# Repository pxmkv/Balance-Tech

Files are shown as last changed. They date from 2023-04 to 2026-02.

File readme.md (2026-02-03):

# Balance-Tech — Reaction-Wheel Self-Balancing Bike (ESP32 + LQR)

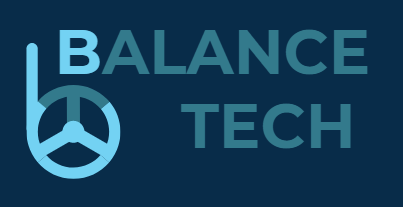
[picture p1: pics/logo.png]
Balance-Tech


A two-wheel self-balancing object reminiscent of a motorcycle, with the ability to **move** and **turn**.  
Balancing is achieved using a **reaction (momentum) wheel** driven by a motor, with a **Kalman filter** for tilt estimation and **LQR state feedback** for control.

> **Safety:** the firmware stops the momentum wheel motor when the tilt exceeds **22°**.

---

## Demo / Photos

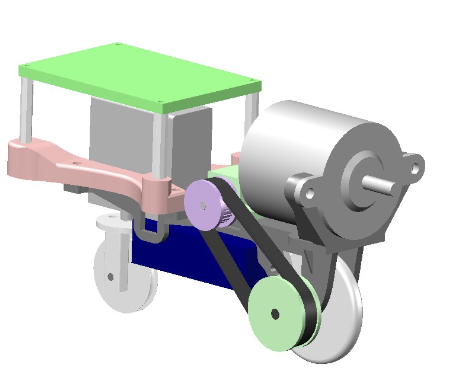
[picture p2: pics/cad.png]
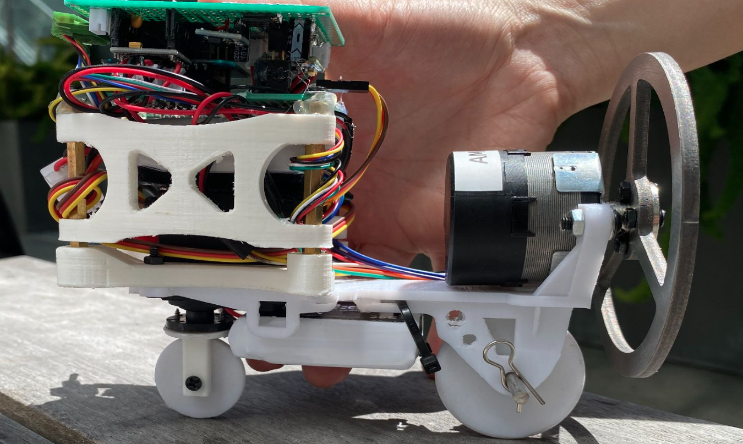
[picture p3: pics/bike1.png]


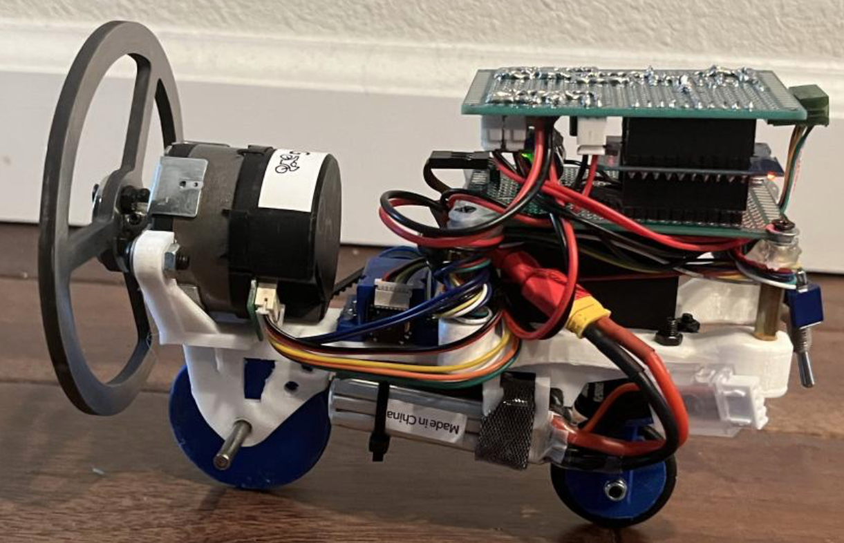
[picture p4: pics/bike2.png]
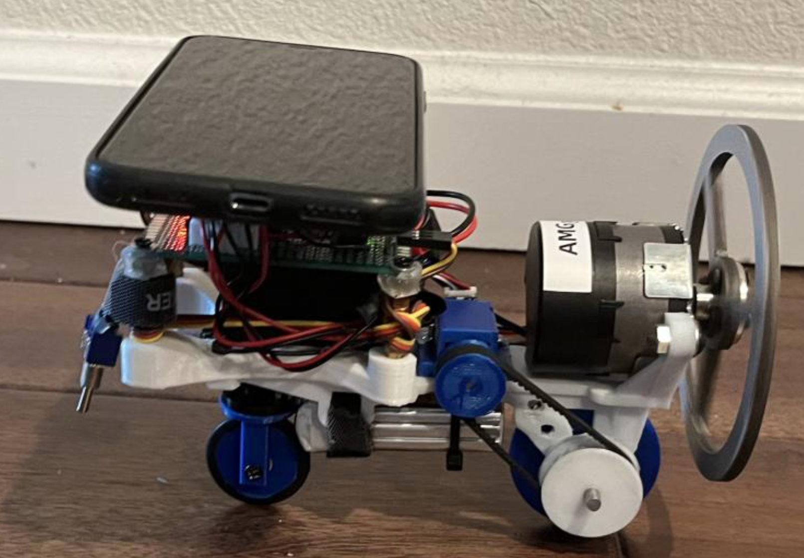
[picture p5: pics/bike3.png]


**Integrated device with labeled actuators and sensors:**

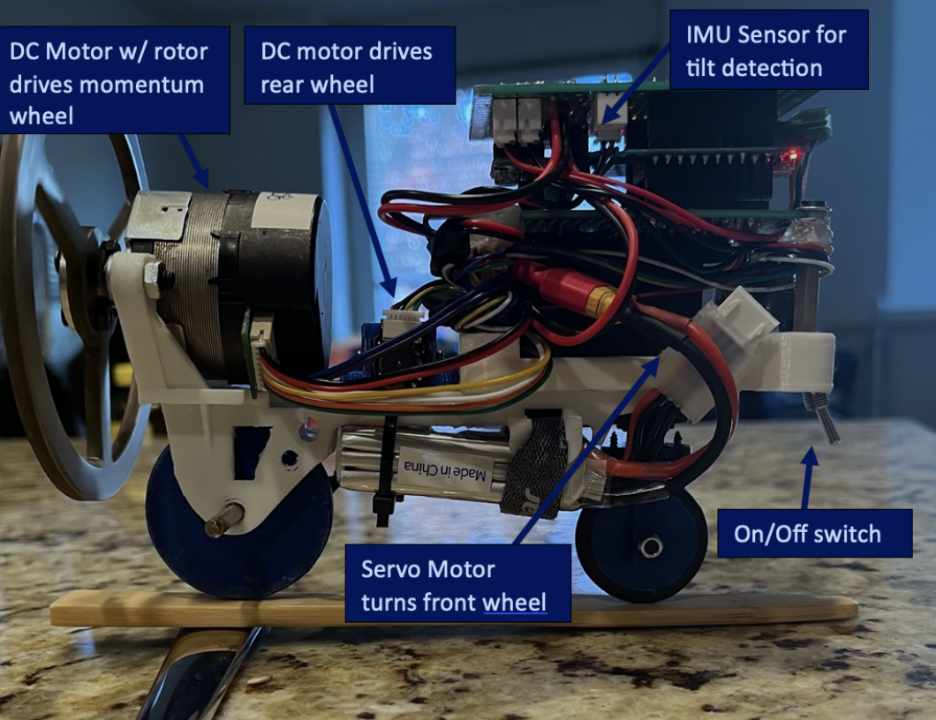
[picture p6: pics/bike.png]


---

## System overview

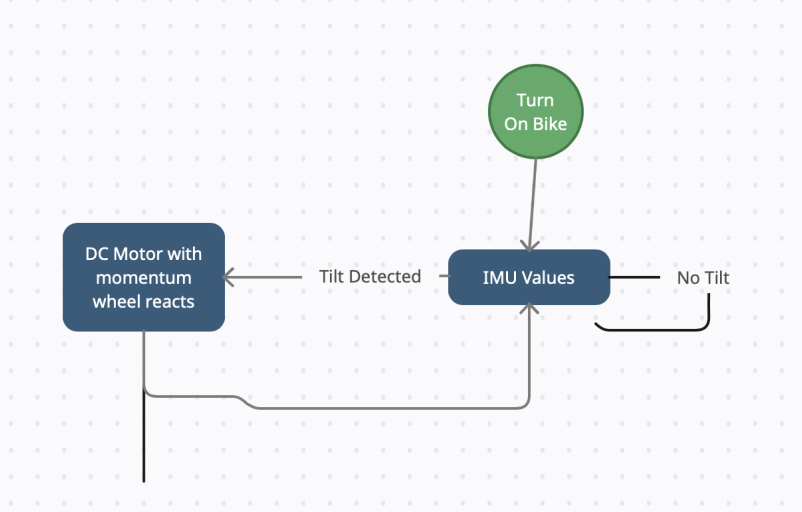
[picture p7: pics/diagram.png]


**Mechanical/coordinate model used in the derivation:**

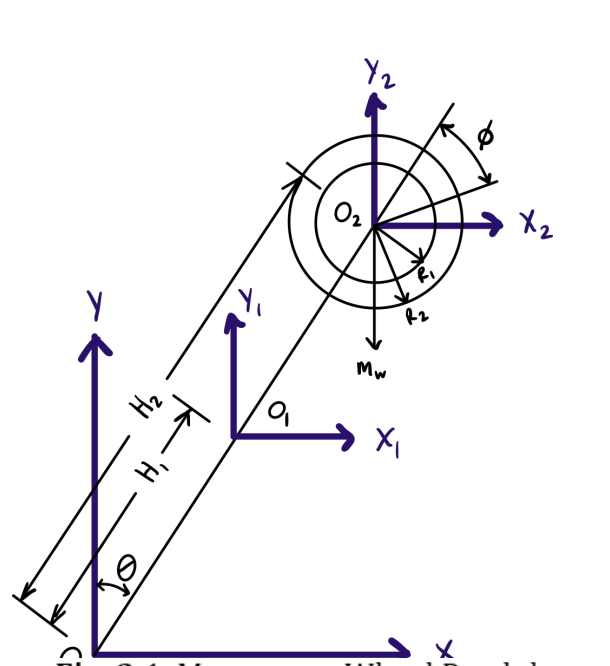
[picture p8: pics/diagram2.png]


**Electronics stack (as built):**

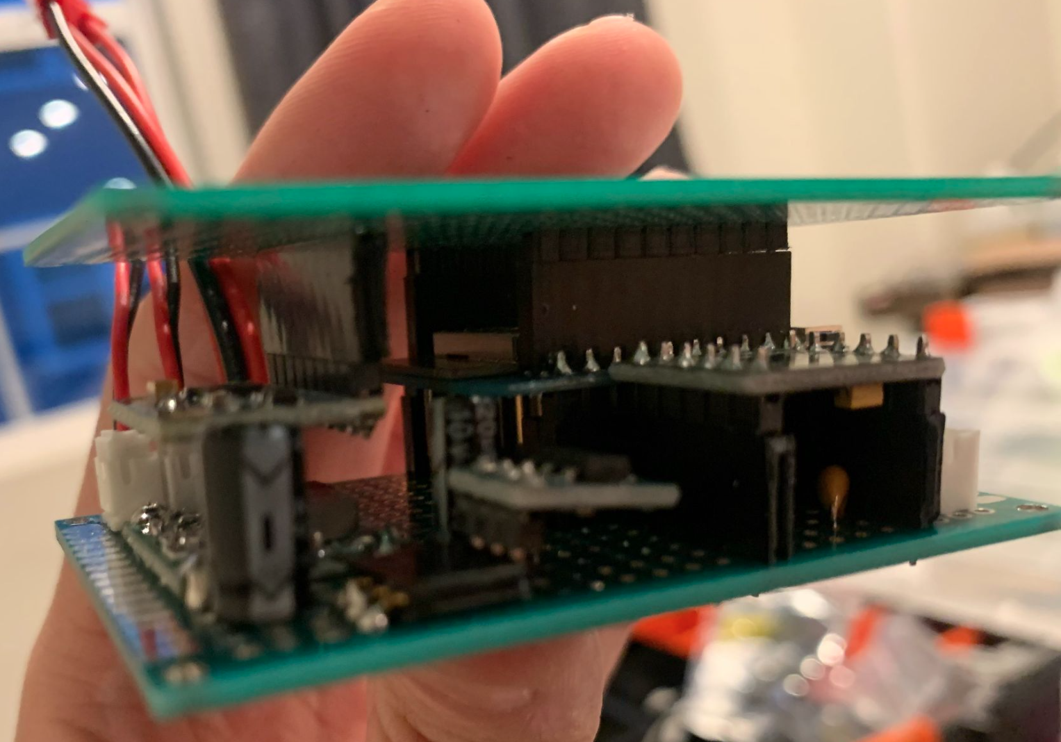
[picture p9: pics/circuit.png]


The bulk of the circuit design lies within a three “story” structure: three circuit boards with ~1 inch spacing.  
Battery power is wired low to reduce center of mass. A buck converter provides adjustable supply and an AMS1117 (DS1117) provides regulation for the MCU.

---

## Repository layout

- `readme.md` — this document  
- `main_LQR/` — Arduino firmware (`main_LQR.ino`) + MATLAB/LQR notes (`main_LQR/readme.md`)
- `schematic/` — wiring reference (PDF)
- `pics/` — images used by the README
- `CAD Files/` — SolidWorks files
- `STL Files/` — printable STLs
- `datasheet/` — key component datasheets
- `LICENSE` — BSD-2-Clause

---

## Hardware

### Actuators
- **Momentum wheel motor**: generates stabilizing torque by accelerating/decelerating the wheel.
- **Rear drive motor**: propels the bike forward/backward.
- **Steering servo**: turns the front wheel.

### Sensors
- **IMU**: MPU6050 (code) / MPU-6000 class (see datasheet)
- **Quadrature encoder** on the momentum wheel motor (speed + position)

### Controller
- **MCU**: WeMOS D1 mini ESP32 (ESP-WROOM-32)

Board reference:

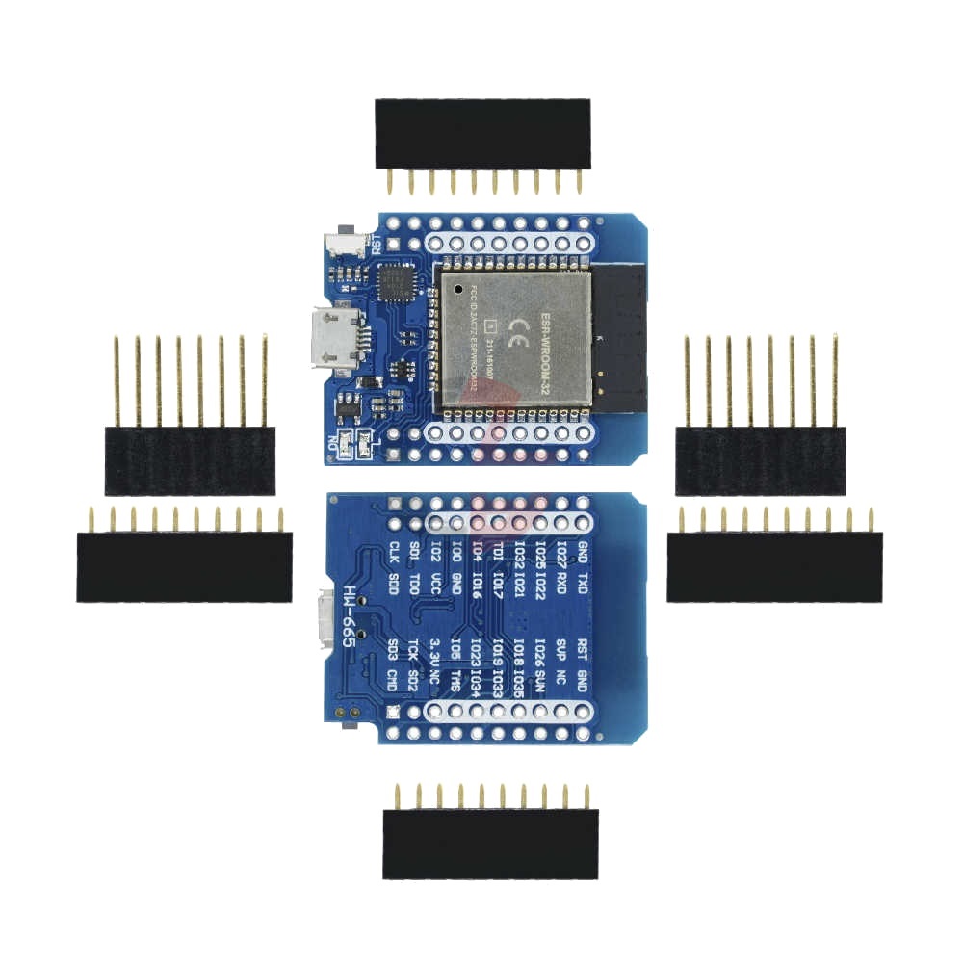
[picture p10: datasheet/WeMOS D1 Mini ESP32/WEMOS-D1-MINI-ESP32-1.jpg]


---

## Wiring / Pin map (firmware defaults)

| Function | GPIO | Notes |
|---|---:|---|
| Momentum wheel PWM | 26 | 20 kHz PWM (`ledc`) |
| Momentum wheel enable/switch | 18 | `M_SW` |
| Momentum wheel direction | 5 | `M_Dir` |
| Encoder A / B | 19 / 23 | `ESP32Encoder.attachHalfQuad(19, 23)` |
| Drive motor PWM (H-bridge) | 33 / 4 | 5 kHz (`D1=33`, `D2=4`) |
| Steering servo PWM | 17 | 50 Hz (`servoChannel`) |
| IMU I²C | SDA=21, SCL=22 | `Wire.begin()` defaults |

Full wiring PDF: [`schematic/sch(just for reference).pdf`](schematic/sch(just%20for%20reference).pdf)

---

## Firmware: build & run

### Toolchain
- Arduino IDE or PlatformIO (Arduino framework)
- Board: “ESP32 Dev Module” (or compatible)

### Libraries
- `ESP32Encoder`
- `I2Cdev` + `MPU6050`
- `Bluepad32`

### Runtime steps
1. Power on the bike.
2. Connect a Bluetooth gamepad (Bluepad32).
3. Calibrate upright offset:
   - **Gamepad:** press **Y + B** (sets `offset = agx`)
   - **Serial:** send `c` (also sets `offset = agx`)
4. Balancing loop runs at ~100 Hz (`loop_time = 10 ms`).

---

## CPU / task structure (ESP32 dual-core)

The firmware pins the remote/gamepad task to core 0, while the balancing loop runs on core 1:

- **CPU Core 1 (`loop`)**
  - Kalman filter (MPU6050 accel + gyro fusion)
  - State computation and LQR control
- **CPU Core 0 (`remote` task)**
  - Read game controller input via Bluepad32
  - Map throttle/brake to drive motor
  - Map joystick to steering servo
  - Provide quick offset calibration via Y+B

---

## Live tuning (Serial)

Send newline-terminated commands:

- `a<value>` → set `K1`
- `s<value>` → set `K2`
- `d<value>` → set `K3`
- `f<value>` → set `K4`
- `o<value>` → set `offset`
- `c` → calibrate (`offset = agx`)

Example:

```txt
a120
s10
d5
f2
```

---

## Control architecture

### State estimation
The IMU provides raw accel/gyro. The code:
- Computes accel tilt (deg) using `atan()`
- Integrates gyro to emphasize short-term dynamics
- Applies a simple Kalman update to fuse accel + gyro (`Kalman_filter()`)

Balancing loop states used in control:
- `euler_angle` (deg): computed as `-agx + offset`
- `gyroXfilter` (deg/s): low-pass filtered angular rate
- `motor_speed` (encoder ticks per loop): `enc_count` each loop
- `motor_pos` (encoder tick accumulator): clamped to `[-110, 110]`

> **Important:** the implementation mixes units (**degrees**, **deg/s**, and **encoder ticks**).  
> The resulting “LQR gains” in firmware should be treated as **tuned state-feedback gains** for these units.

#### Kalman filter (tilt fusion in firmware)

The firmware implements **two independent 1D (scalar) Kalman filters**—one for X tilt (`agx`) and one for Y (`agy`).  
For balancing, the controller mainly uses **X-axis tilt**.

**Accelerometer “measurement”** (deg):

$$
z_k = a_{x,k} = \tan^{-1}\!\left(\frac{a_y}{a_z}\right)\cdot\left(-\frac{180}{\pi}\right)
$$

**Gyro rate + discrete integration** (with $\Delta t=\texttt{loop time}/1000$):

$$
\omega_{g,k} = -\frac{(g_x-g_{x0})}{\texttt{GyroRatio}},\qquad
\hat{\theta}^{-}_k = \hat{\theta}_{k-1}+\omega_{g,k}\,\Delta t
$$

**Scalar Kalman update** (with online-estimated $R_k$):

$$
\begin{aligned} P_k^- &= P_{k-1}+Q \\[2pt] K_k &= \frac{P_k^-}{P_k^-+R_k} \\[2pt] \hat{\theta}_k &= \hat{\theta}_k^- + K_k\left(z_k-\hat{\theta}_k^-\right) \\[2pt] P_k &= (1-K_k)P_k^- \end{aligned}
$$

**How $R_k$ is obtained in this project:**  
The code keeps a sliding window of the last 10 accelerometer angles (`a_x[]`) and uses their sample variance as the measurement noise:

$$
\bar{a}_x = \frac{1}{10}\sum_{i=1}^{10} a_{x,i},\qquad
R_k = \frac{1}{9}\sum_{i=1}^{10}\left(a_{x,i}-\bar{a}_x\right)^2
$$

**Tuned constants / initial values (from `main_LQR.ino`):**

$$
P_0=1,\qquad Q=0.0025
$$

**Gyro rate used by the LQR state feedback:**  
In code, the gyro-derived angle rate is converted/scaled to deg/s and then low-pass filtered:

$$
\dot{\theta}_{\mathrm{LPF}}[k]=\alpha\,\dot{\theta}[k]+(1-\alpha)\,\dot{\theta}_{\mathrm{LPF}}[k-1],\qquad \alpha=0.4
$$

Code reference (for clarity):

```txt
v_gyrox     = -gyrox * 1000 / loop_time
gyroXfilter = 0.4 * v_gyrox + 0.6 * gyroXfilter

### State feedback (as implemented)
The controller in `main_LQR.ino` computes:

```txt
u = K1*euler_angle + K2*gyroXfilter - K3*motor_speed - K4*motor_pos
PWM = clamp(u, -255, 255)
```

And applies `PWM` to the momentum wheel motor. If `|euler_angle| > 22°`, the momentum wheel motor output is forced to zero.

---

## Engineering analysis

### A) External torque requirement (gravity vs. reaction wheel)

The system’s center of mass is above its pivot point, making it inherently unstable.  
If the Euler angle reaches a threshold of 22°, the motor is programmed to stop. Taking that as the maximum operating angle, the maximum gravitational torque is:

$$
T_g = H_1\,M\,g\,\sin(22^\circ) = 0.134~\mathrm{N\cdot m}
$$

The following calculations verify the reaction wheel’s ability to apply a neutralizing torque of equal magnitude or higher.

Motor rotor inertia (solid disk approximation):

$$
I_{\mathrm{motor}} = \frac{1}{2}MR^2 = 2.942\times 10^{-5}~\mathrm{kg\cdot m^2}
$$

Rated motor torque:

$$
T_{\mathrm{motor,rated}} = 0.0385~\mathrm{N\cdot m}
$$

Max angular acceleration:

$$
\alpha_{\max} = \frac{T_{\mathrm{motor,rated}}}{I_{\mathrm{motor}}}
= 1308~\mathrm{rad/s^2}
$$

Reaction wheel inertia (thick ring approximation):

$$
I_w = \frac{1}{2}M\left(R_1^2 + R_2^2\right) = 2.699\times 10^{-4}~\mathrm{kg\cdot m^2}
$$

Max reaction wheel torque:

$$
T_{w,\max} = I_w\,\alpha_{\max} = 0.343~\mathrm{N\cdot m}
$$

Additionally, the performance curve of the BLDC motor shows it is capable of delivering sufficient torque:

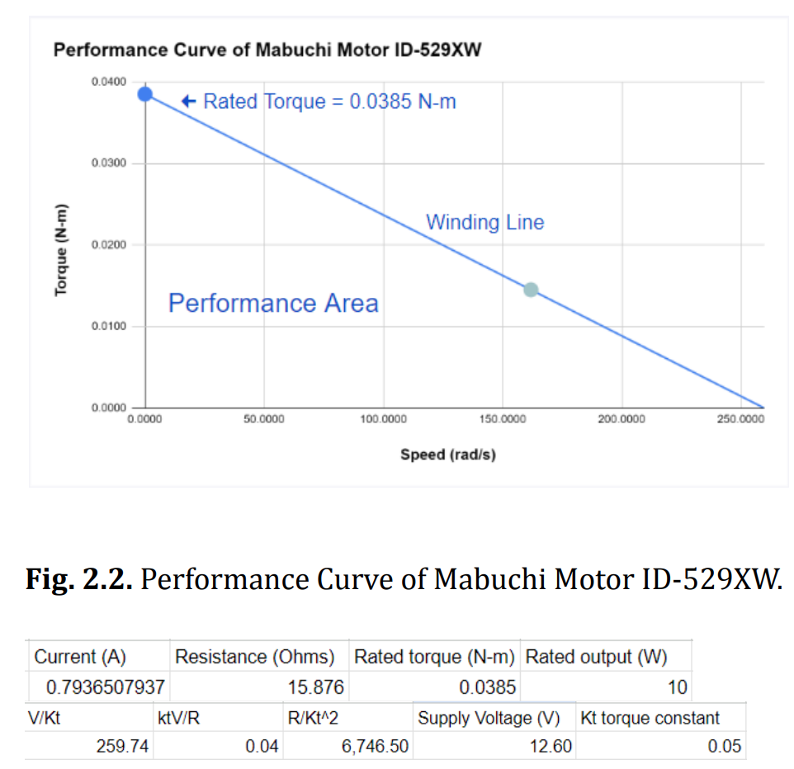
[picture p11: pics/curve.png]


---

### B) Optimization of the K gain matrix (LQR)

There are four parameters that describe the system state:
1) Euler angle  
2) angular velocity  
3) reaction wheel speed  
4) reaction wheel position  

A feedback approach is used to bring actual states toward desired states. The gain matrix is computed by LQR to minimize both state error and control effort.

Control law:

$$
u = -K\left(x-x_{\mathrm{desired}}\right)
$$

Quadratic cost function:

$$
J(u)=\int_{0}^{\infty}\left(x^TQx+u^TRu+2x^TNu\right)\,dt
$$

In MATLAB:

$$
K = \mathrm{lqr}(A,B,Q,R)
$$

And for the continuous-time algebraic Riccati equation (CARE):

$$
K = R^{-1}\left(B^TP\right)
$$

$$
A^TP + PA - (PB)R^{-1}(B^TP) + Q = 0
$$

---

### C) Lagrange modeling (reaction-wheel inverted pendulum)

Following the project derivation, the Lagrangian is formed from kinetic and potential energy terms:

$$
L = K_1 + K_2 - V
$$

where $K_1$ and $K_2$ are kinetic energy terms and $V$ is the potential energy.

Euler–Lagrange equations:

$$
\frac{d}{dt}\left(\frac{\partial L}{\partial \dot{\theta}}\right)-\frac{\partial L}{\partial \theta}=T_g,\qquad
\frac{d}{dt}\left(\frac{\partial L}{\partial \dot{\phi}}\right)-\frac{\partial L}{\partial \phi}=T_M
$$

Linearized dynamics used in the report:

$$
T_g = (a+I_w)\ddot{\theta} + I_w\ddot{\phi} = b\theta
$$

where

$$
a = m_bH_1^2 + m_wH_2^2,\qquad
b = (m_bH_1 + m_wH_2)g
$$

and

$$
T_M = I_w(\ddot{\theta}+\ddot{\phi})
$$

---

### D) State-space form

$$
\dot{x}=Ax+Bu,\qquad
x=\begin{bmatrix}
\theta\\[2pt]
\dot{\theta}\\[2pt]
\phi\\[2pt]
\dot{\phi}
\end{bmatrix},\quad
u=T_M
$$

$$
\begin{aligned}
\begin{bmatrix}
\dot{\theta}\\[2pt]
\ddot{\theta}\\[2pt]
\dot{\phi}\\[2pt]
\ddot{\phi}
\end{bmatrix}
&=
\underbrace{\begin{bmatrix}
0 & 1 & 0 & 0\\[2pt]
\frac{b}{a} & 0 & 0 & 0\\[2pt]
0 & 0 & 0 & 1\\[2pt]
-\frac{b}{a} & 0 & 0 & 0
\end{bmatrix}}_{A}
\begin{bmatrix}
\theta\\[2pt]
\dot{\theta}\\[2pt]
\phi\\[2pt]
\dot{\phi}
\end{bmatrix}
+
\underbrace{\begin{bmatrix}
0\\[2pt]
-\frac{1}{a}\\[2pt]
0\\[2pt]
\frac{a+I_w}{aI_w}
\end{bmatrix}}_{B}\,T_M
\end{aligned}
$$

---

### E) Q / R selection

$$
Q=
\begin{bmatrix}
1 & 0 & 0 & 0\\[2pt]
0 & 1 & 0 & 0\\[2pt]
0 & 0 & 0.001 & 0\\[2pt]
0 & 0 & 0 & 1
\end{bmatrix},\qquad
R=1
$$

---

### F) Gains

Final tuned gains in firmware (`main_LQR.ino`):

$$
K =
\begin{bmatrix}
108.4496 & 9.6210 & 5.00 & 1.80
\end{bmatrix}
$$

For the full MATLAB derivation and intermediate results, see: [`main_LQR/readme.md`](main_LQR/readme.md)

---

## CAD / STL

- SolidWorks source: [`CAD Files/`](CAD%20Files/)
- Printable STLs: [`STL Files/`](STL%20Files/)

---

## References

[1] Olfati-Saber, Reza. “Global Stabilization of a Flat Underactuated System: The Inertia Wheel Pendulum.” CDC 2001.  
[2] Çakan, Abdullah, and Ümit Önen. “Multibody Modeling and Balance Control of a Reaction Wheel Inverted Pendulum Using LQR Controller.” 2021.  
[3] Lacey, Tony. “Tutorial: The Kalman Filter.” MIT.  
[4] Nguyen, Hau; Cu, Minh Phuoc. “LQR and Fuzzy Control for Reaction Wheel Inverted Pendulum Model.” 2019.  
[5] Leroy, Etienne. “Guide to Gyro and Accelerometer With Arduino Including Kalman Filtering.” 2011.  
[6] Polotski, Vladimir. “Kalman filter, how do I choose initial P0?” 2017.  
[7] Vathsangam, Harsh. “Complementary filter - My IMU estimation experience.” 2010.  
[8] Abbeel, Pieter. “Optimal Control for Linear Dynamical Systems and Quadratic Cost.” UC Berkeley.  
[9] Sears-Collins, Addison. “Combine the Extended Kalman Filter With LQR.” 2020.  
[10] Quesada, Ricardo. “bluepad32 Arduino platform notes.”  
[11] “1-Axis Attitude Control Module with ATOM.” M5Stack Projects, 2020.

---

## License
BSD-2-Clause — see [`LICENSE`](LICENSE).

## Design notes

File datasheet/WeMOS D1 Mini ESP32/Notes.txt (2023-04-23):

Buy: https://artofcircuits.com/product/wemos-d1-mini-esp32-esp-wroom-32

Description

The WEMOS D1 Mini ESP32 Development Board includes the ESP32 SoC, USB-to-Serial (CP2102) IC, and all the necessary passive components, comes ready for plugging into your computer’s USB port and loading up custom firmware.

The  WEMOS D1 Mini ESP32 board offers an inexpensive solution for making internet-connected and bluetooth-controllable devices. Moreover, its small footprint and accompanying wide range of shields make it an ideal solution for quickly prototyping IoT projects in a compact amount of space.

Even though the WeMos family of boards was originally developed for the ESP8266, the design of this WEMOS D1 Mini ESP32 allows for using the ESP32 with most of the original shields. This represents a great addition to an already superb ecosystem for developing internet-capable applications (Internet Of Things or IoT).

Features

PCB-mounted antenna
Onboard Micro-USB connector (i.e., USB Micro-B)
SoC: ESP32 FCC certified Wi-Fi and Bluetooth module (ESP-WROOM-32 Module)
USB-to-Serial: Silicon Labs CP2102 USB to UART Bridge
GPIO: 3×UART, 3×SPI, 2×I2S, 18×ADC input channels, 2×DAC output channels, 2×I2C, PWM/timer input/output available on every GPIO pin, OpenOCD debug interface, SDIO master/slave (50 MHz), external SPI flash (up to 16MB), and SD-card interface support
Size: 39mm × 31mm
Voltage Reg.: RT9013 500mA LDO
Power Input: 3.0~5.5VDC

Technical Specifications

Analog-to-Digital Converter (ADC) – Up to 16 channels of 12-bit SAR ADC’s. The ADC range can be set, in firmware, to either 0-1V, 0-1.4V, 0-2V, or 0-4V – no more weird 0-1V ADC!
Digital-to-Analog Converter (DAC) – Two 8-bit DAC’s to produce true analog voltages
Pulse-Width Modulation (PWM) – Up to 16 channels of PWM-capable pins for dimming LEDs or controlling motors
Touch Sensor – 10 GPIOs feature capacitive sensing; make a 10-key buttonpad!
UART – Two UART interfaces, one is used to load code serially. They feature flow control, and support IrDA too!
I2C, SPI, I2S – There are two I2C and four SPI interfaces to hook up all sorts of sensors and peripherals, plus two I2S interfaces if you want to add sound to your project.
Documents and Downloads
WeMOS D1 Mini ESP32 Schematic
ESP32 Module Wiki page
ESP32 Datasheet
ESP32 Technical Reference manual
ESP32 RTOS SDK on Github
A related page on ESP32
A video tutorial on ESP32 and Arduino IDE
ESP8266 and ESP32 Differences in One Single Table

Package Includes

1x Wemos D1 Mini ESP32 – ESP-WROOM-32 Development Board (Tested and QC-OK)
4x 10-Pin Male to Female Standard headers
2x 8-Pin Male to Female Stackable Headers

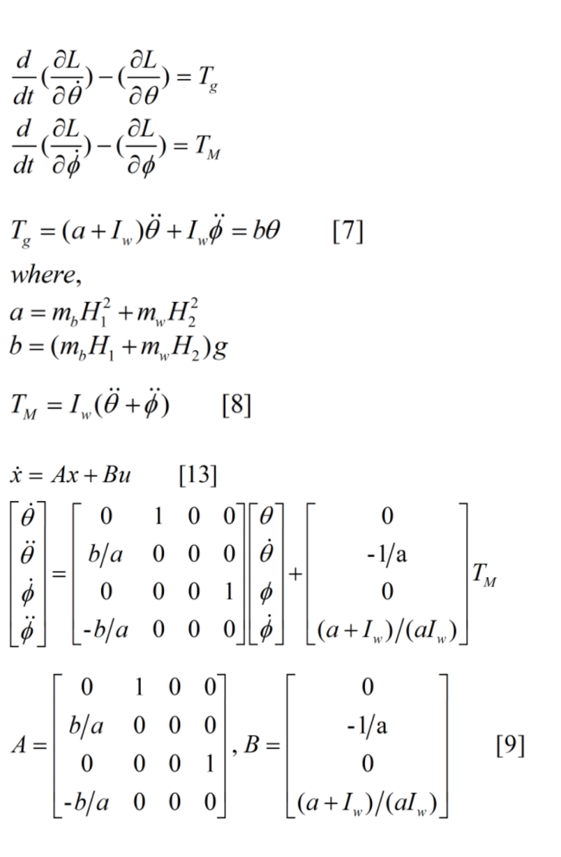
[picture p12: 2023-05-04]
pics/equation5.png

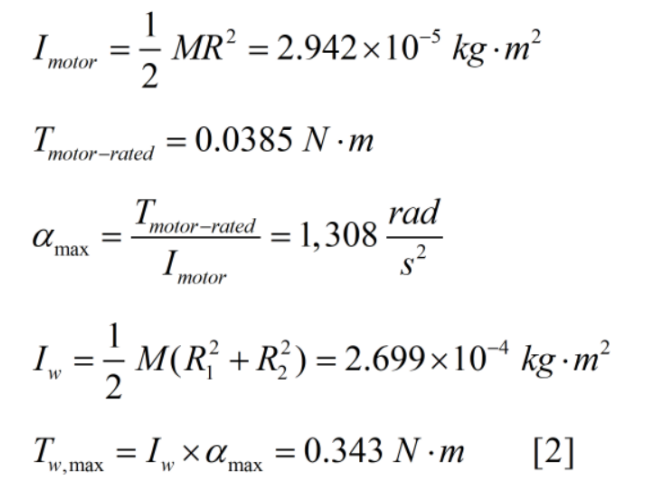
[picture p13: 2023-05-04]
pics/equation2.png

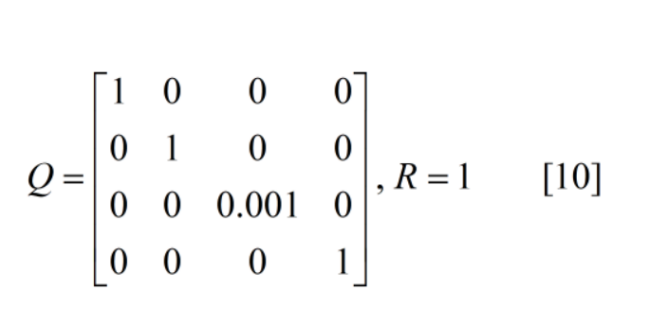
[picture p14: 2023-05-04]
pics/equation6.png

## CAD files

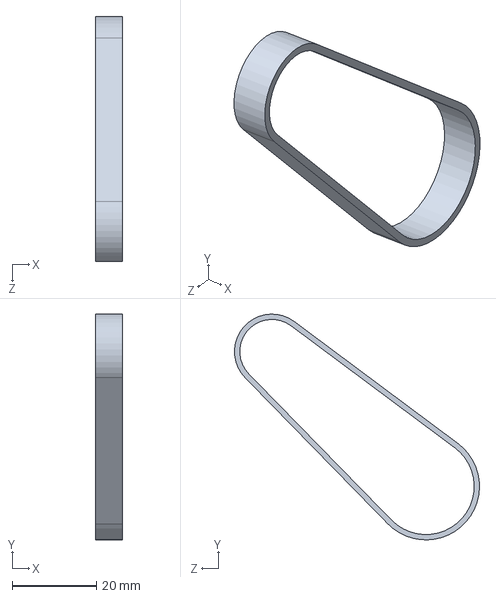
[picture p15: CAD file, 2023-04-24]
CAD Files/Belt.SLDPRT
6.50 x 53.6 x 58.1 mm

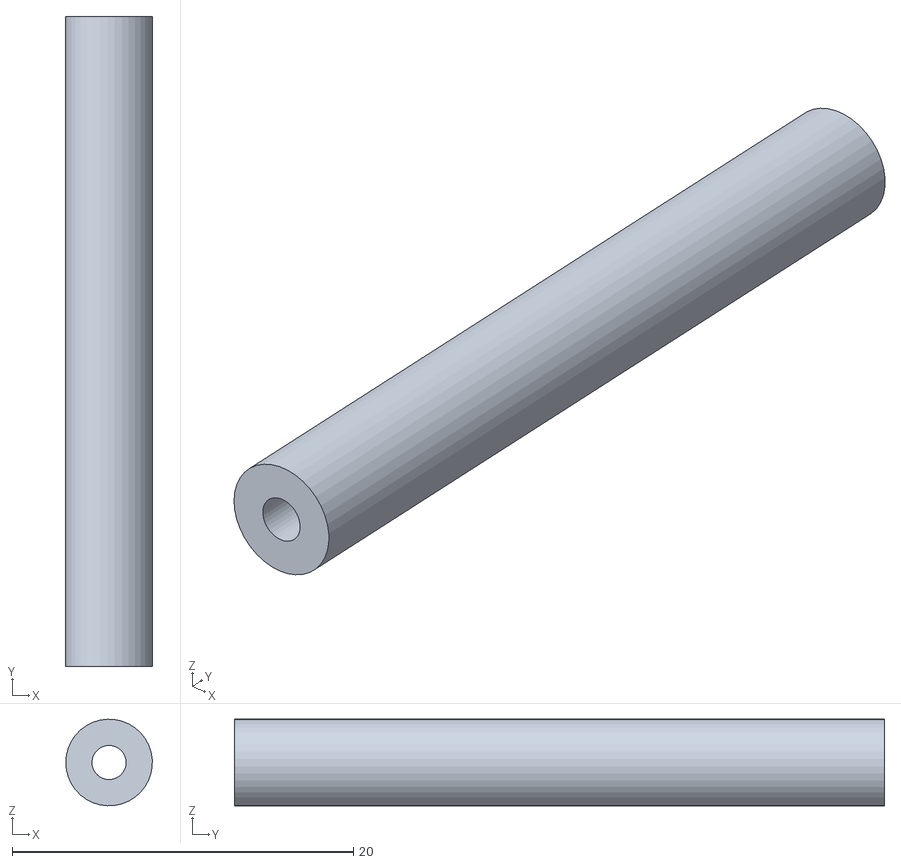
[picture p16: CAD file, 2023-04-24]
STL Files/Assem1 - Circuit Bar-8.STL
5.07 x 38.1 x 5.08

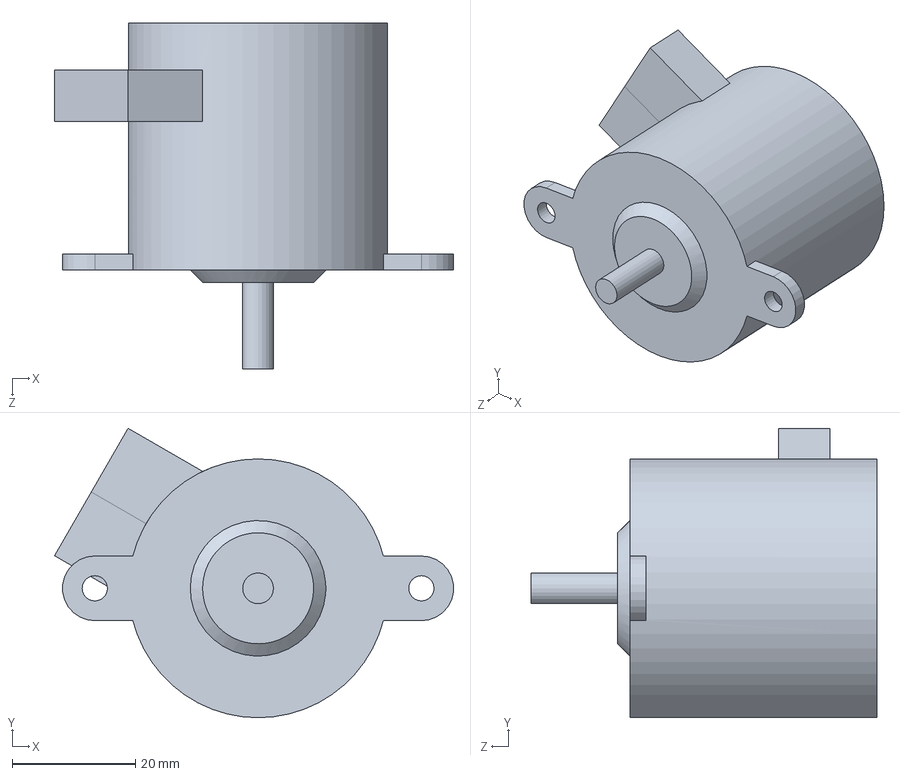
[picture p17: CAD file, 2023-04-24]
CAD Files/MomentumWheelMotor.SLDPRT
64.8 x 47.0 x 56.1 mm

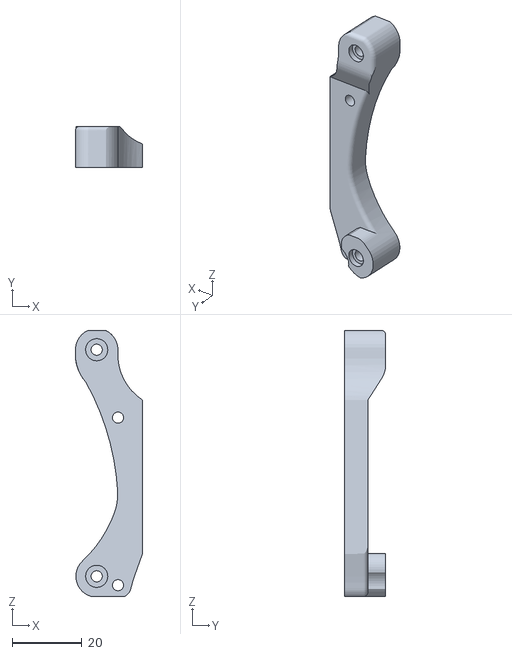
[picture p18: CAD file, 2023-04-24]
STL Files/Assem1 - Part1^Assem1-1.STL
19.2 x 11.9 x 76.2

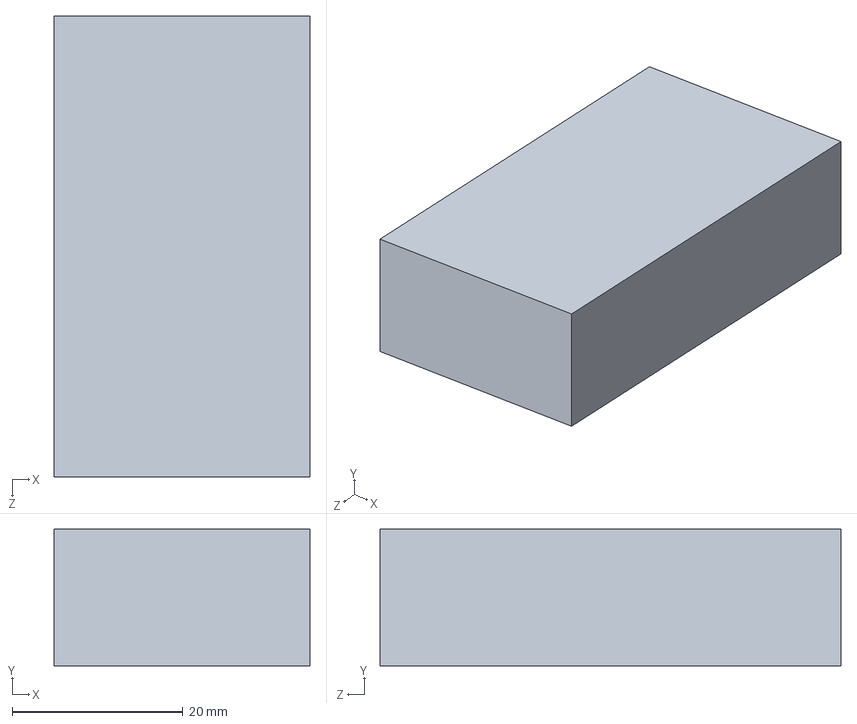
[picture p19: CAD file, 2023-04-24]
CAD Files/Battery.SLDPRT
30.0 x 16.0 x 54.0 mm

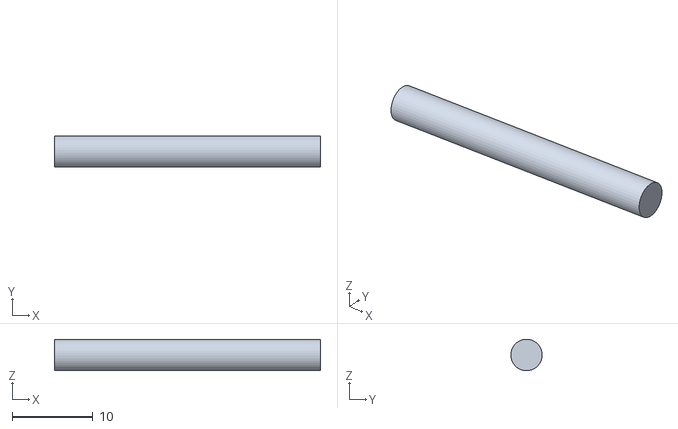
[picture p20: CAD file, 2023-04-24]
STL Files/Assem1 - Front Axle^Assem1-1.STL
33.0 x 3.90 x 3.89

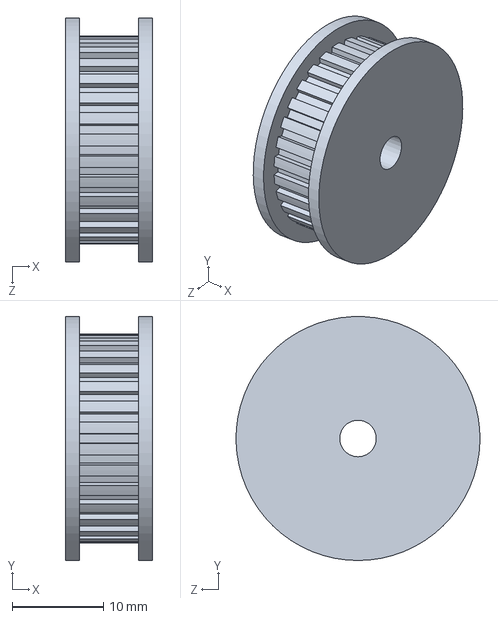
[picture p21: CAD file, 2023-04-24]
CAD Files/BigGear.SLDPRT
9.50 x 26.7 x 26.7 mm

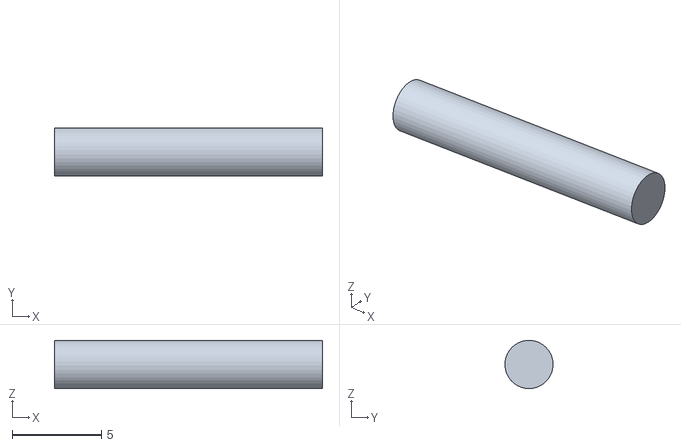
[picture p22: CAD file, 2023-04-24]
STL Files/Assem1 - Rear Axle-3.STL
15.0 x 2.70 x 2.70

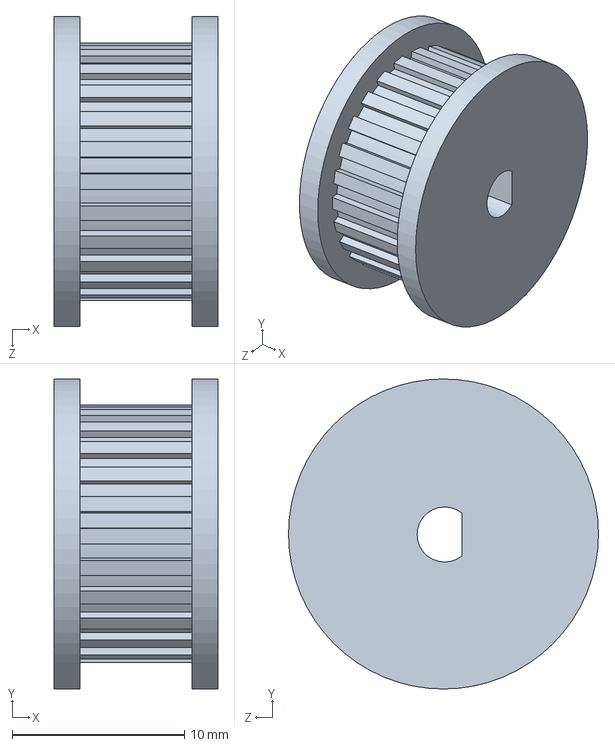
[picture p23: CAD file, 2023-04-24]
CAD Files/GearSmaal.SLDPRT
9.50 x 18.0 x 18.0 mm

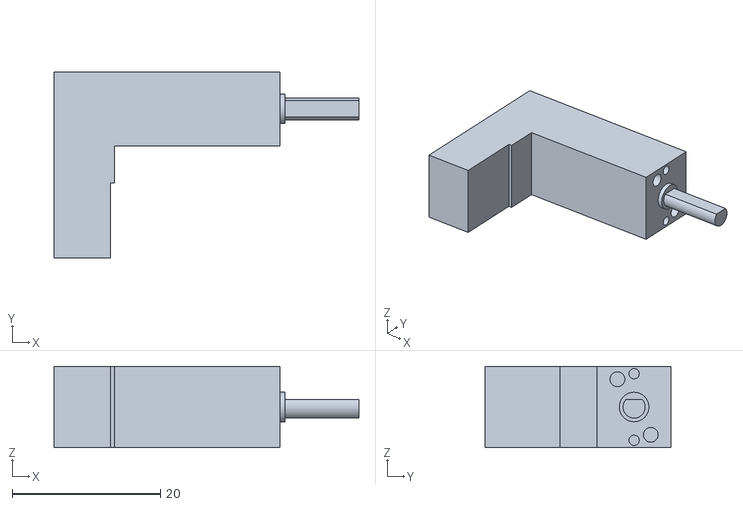
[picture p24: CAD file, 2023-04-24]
STL Files/Assem1 - Rear Motor-1.STL
41.2 x 25.2 x 11.0

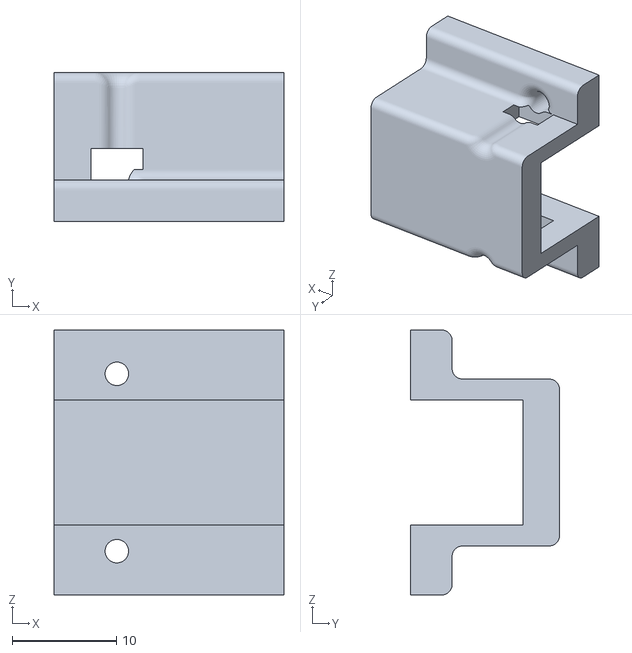
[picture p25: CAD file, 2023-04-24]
STL Files/Assem1 - TabRearMotor^Assem1-1.STL
22.0 x 14.3 x 25.4

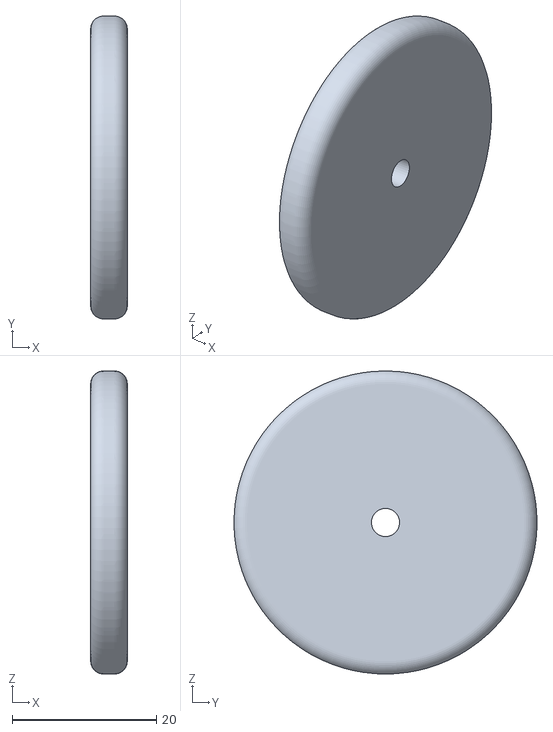
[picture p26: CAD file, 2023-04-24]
STL Files/Assem1 - Front wheel^Assem1-1.STL
5.08 x 42.0 x 42.0

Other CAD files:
STL Files/Assem1 - Circuit Bar-9.STL
CAD Files/Front Axle.SLDPRT
CAD Files/Rear Axle.SLDPRT
STL Files/Assem1 - Belt^Assem1-1.STL
CAD Files/Circuit Bar.SLDPRT
CAD Files/Rear Motor.SLDPRT
CAD Files/Circuit Board.SLDPRT
CAD Files/Front wheel.SLDPRT
CAD Files/Rear wheel.SLDPRT
CAD Files/ServoMotor.SLDPRT
CAD Files/Steering.SLDPRT
CAD Files/Tab Battery.SLDPRT
CAD Files/TabRearMotor.SLDPRT
STL Files/Assem1 - Battery-3.STL
STL Files/Assem1 - BigGear^Assem1-1.STL
STL Files/Assem1 - Circuit Bar-1.STL
STL Files/Assem1 - Circuit Bar-5.STL
STL Files/Assem1 - GearSmaal-1.STL
STL Files/Assem1 - MirrorPart1^Assem1-2.STL
STL Files/Assem1 - MomentumWheelMotor-1.STL
STL Files/Assem1 - Rear wheel-2.STL
STL Files/Assem1 - ServoMotor-1.STL
STL Files/Assem1 - Steering.STL
STL Files/Assem1 - Tab Battery-1.STL
STL Files/Assem1 - Tab Battery-2.STL

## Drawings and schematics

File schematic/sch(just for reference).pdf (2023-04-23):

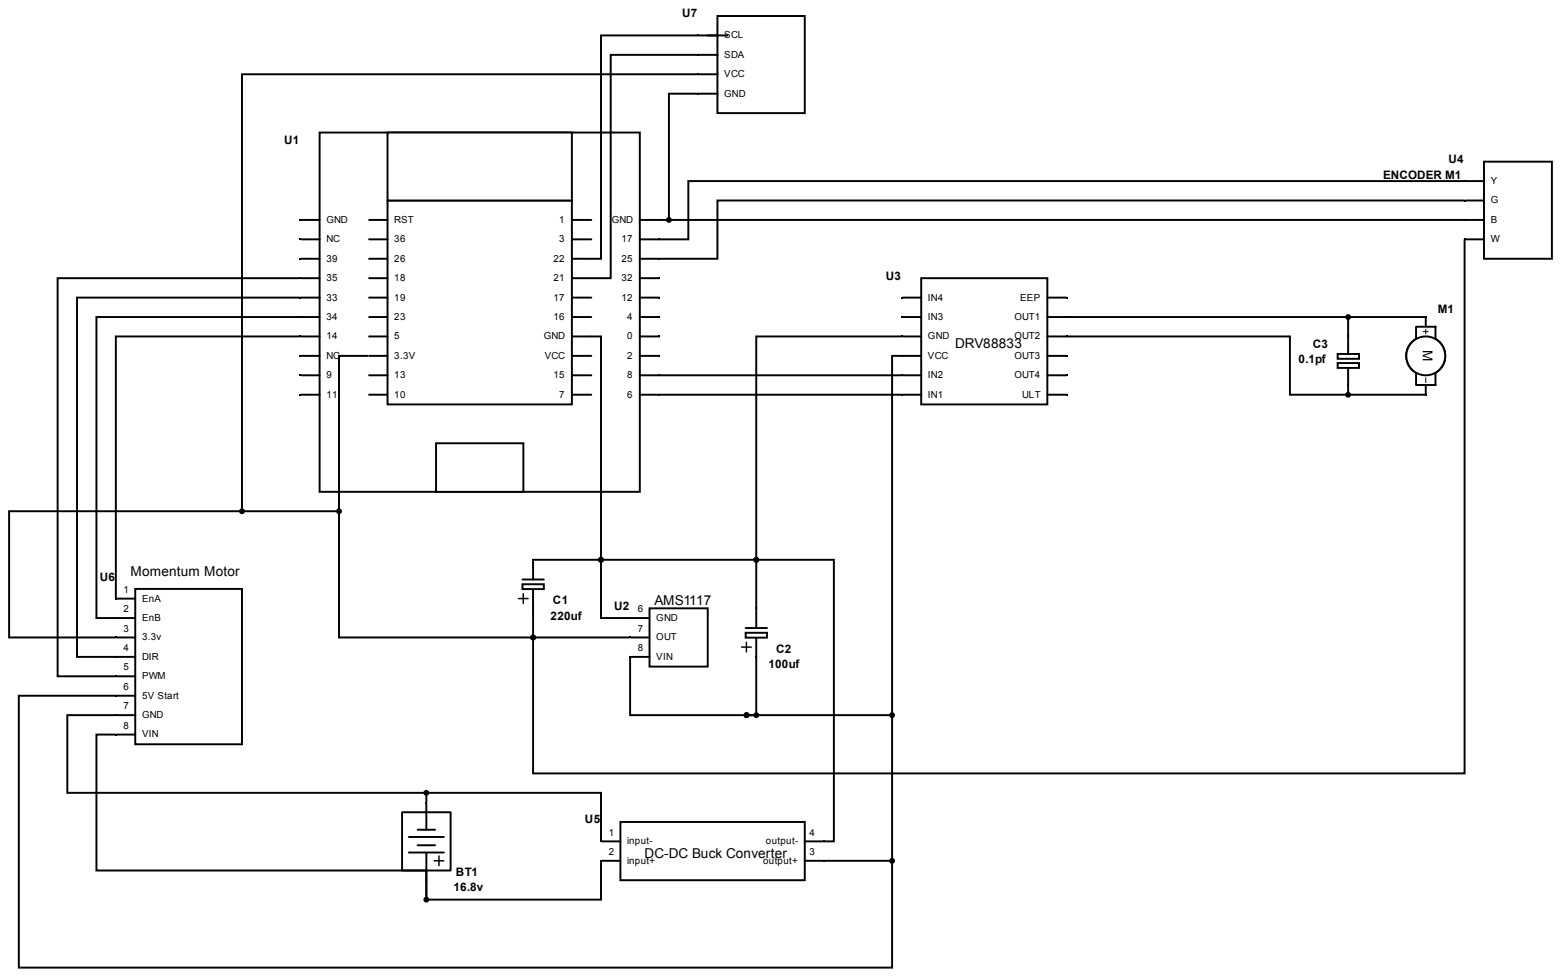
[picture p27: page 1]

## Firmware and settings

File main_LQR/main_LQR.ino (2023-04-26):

#include <ESP32Encoder.h>
#include "Wire.h"
#include "I2Cdev.h"
#include "MPU6050.h"
#include <Bluepad32.h>

#define ledPin 2
#define M_PWM 26
#define M_SW 18
#define M_Dir 5
#define D1 33
#define D2 4

GamepadPtr myGamepads[BP32_MAX_GAMEPADS];

MPU6050 accelgyro;
ESP32Encoder encoder;
long enc_count;


const int m_freq = 20000;
const int resolution = 8;
int MAX_PWM_VOLTAGE = 255;
const int M_Wheel = 1;
const int DChannel_1 = 2;
const int DChannel_2 = 3;
const int servoChannel = 4;
const int servo_freq = 50;
const int D_freq = 5000;

int16_t motor_speed;
int32_t motor_pos;

                             
int16_t ax, ay, az, gx, gy, gz;             //raw data from mpu6050
float aax=0, aay=0, agx=0, agy=0, agz=0;    //angle var
long axo = 0, ayo = 0, azo = 0;             //acc offset
long gxo = 0, gyo = 0, gzo = 0;             //gyr offset

float pi = 3.1415926;
float AcceRatio = 16384.0;                  //Ratio for acc 
float GyroRatio = 131.0;                    //Ratio for gyr 

uint8_t n_sample = 8;                       //num of filter sample 
float aaxs[8] = {0}, aays[8] = {0};         //x,y queoe
long aax_sum, aay_sum;                      //x,y sample sum

float a_x[10]={0}, a_y[10]={0} ,g_x[10]={0} ,g_y[10]={0}; //variance
float Px=1, Rx, Kx, Sx, Vx, Qx;             //Kalman variable for x
float Py=1, Ry, Ky, Sy, Vy, Qy;             //Kalman variable for y

float euler_angle;
float v_gyrox;
/*LQR Const*/
float offset=0;

float K1 = 108.4496;
float K2 = 9.6210;
float K3 = 5.00;
float K4 = 1.80;
long currentT, previousT_1, previousT_2 = 0;  
float loop_time=10;
float gyroXfilter;



int servoPin = 17;


int counter=0;  

void setup() {
  Serial.begin(115200);

  /* M_Wheel setup */
  pinMode(ledPin, OUTPUT);
  pinMode(M_SW, OUTPUT);
  pinMode(M_Dir, OUTPUT);
  ledcSetup(M_Wheel , m_freq, resolution);
  ledcAttachPin(M_PWM, M_Wheel);

  ledcSetup(DChannel_1, D_freq, resolution);
  ledcSetup(DChannel_2, D_freq, resolution);
  ledcAttachPin(D1, DChannel_1);
  ledcAttachPin(D2, DChannel_2);

  ledcSetup(servoChannel, servo_freq, resolution);
  ledcAttachPin(servoPin, servoChannel);
  

  ESP32Encoder::useInternalWeakPullResistors = UP; // Enable the weak pull up resistors
  encoder.attachHalfQuad(19, 23); // Attache pins for use as encoder pins
  encoder.setCount(0);  // set starting count value after attaching

/*Initial MPU */
  Wire.begin();
  accelgyro.initialize();   
               
/*Initial Kalman Filter*/
  unsigned short times = 200;             //sample times
  for(int i=0;i<times;i++){
    accelgyro.getMotion6(&ax, &ay, &az, &gx, &gy, &gz); //read raw data from mpu
    axo += ax; ayo += ay; azo += az;      
    gxo += gx; gyo += gy; gzo += gz;
  }
  axo /= times; ayo /= times; azo /= times; //calculate offset
  gxo /= times; gyo /= times; gzo /= times;
  



  BP32.setup(&onConnectedGamepad, &onDisconnectedGamepad);
  BP32.forgetBluetoothKeys();
  xTaskCreatePinnedToCore(remote, "remote function", 10000, NULL, 1, NULL,  0); // CPU Core 0
}


void loop() {//CPU Core 1
 
  currentT = millis();
  Set_K_value(); // a=k1 s=k2 d=k3 f=k4 o=offset c=calibrate


  if (currentT - previousT_1 >= loop_time) {
  Kalman_filter();
  euler_angle=-agx+offset;
  enc_count=encoder.getCount();
  motor_speed=enc_count;
  encoder.setCount(0);
  gyroXfilter = 0.4 * v_gyrox + (1 - 0.4) * gyroXfilter;
  motor_pos += motor_speed;
  motor_pos = constrain(motor_pos, -110, 110); //110 ticks per rev

  int lqr = constrain(K1 * euler_angle + K2 * gyroXfilter - K3 * motor_speed - K4 * motor_pos, -255, 255); //Linear–quadratic regulator
  M_Motor(-lqr);
  
  //aax, aay, agx, agy, agz
  /* Print out the values */

  if (counter>5){
  Serial.print("AGX: ");
  Serial.print(euler_angle);Serial.print(",");
  Serial.print(gyroXfilter);Serial.print(",");
  Serial.print(motor_pos);Serial.print(",");
  Serial.print(motor_speed);Serial.print(",");
  Serial.print(-lqr);Serial.print(",");Serial.print(offset);
  Serial.println();counter=0;
  }counter++;

  previousT_1 = currentT;
  
  }
}

void Kalman_filter(){

  accelgyro.getMotion6(&ax, &ay, &az, &gx, &gy, &gz); //raw data from MPU

  float accx = ax / AcceRatio;              
  float accy = ay / AcceRatio;              
  float accz = az / AcceRatio;             

  aax = atan(accy / accz) * (-180) / pi;    //angle between level and x
  aay = atan(accx / accz) * 180 / pi;       //angle between level and y

  aax_sum = 0;                              
  aay_sum = 0;
  for(int i=1;i<n_sample;i++){
    aaxs[i-1] = aaxs[i];
    aax_sum += aaxs[i] * i;
    aays[i-1] = aays[i];
    aay_sum += aays[i] * i;
  }
  aaxs[n_sample-1] = aax;
  aax_sum += aax * n_sample;
  aax = (aax_sum / (11*n_sample/2.0)) * 9 / 7.0; //0-90°
  aays[n_sample-1] = aay;                        
  aay_sum += aay * n_sample;                     
  aay = (aay_sum / (11*n_sample/2.0)) * 9 / 7.0;

  float gyrox = - (gx-gxo) / GyroRatio * loop_time/1000; //x Angular velocity
  float gyroy = - (gy-gyo) / GyroRatio * loop_time/1000; //y Angular velocity
  agx += gyrox;                             //Integration of x Angular velocity
  agy += gyroy;                             //Integration of x Angular velocity

  /* kalmen start */
  Sx = 0; Rx = 0;
  Sy = 0; Ry = 0;
  for(int i=1;i<10;i++){                 //avg sample 
    a_x[i-1] = a_x[i];                      
    Sx += a_x[i];
    a_y[i-1] = a_y[i];
    Sy += a_y[i];
  }
  a_x[9] = aax;
  Sx += aax;
  Sx /= 10;                                 //x avg spd
  a_y[9] = aay;
  Sy += aay;
  Sy /= 10;                                 //y avg spd

  for(int i=0;i<10;i++){
    Rx += sq(a_x[i] - Sx);
    Ry += sq(a_y[i] - Sy);
  }
  Rx = Rx / 9;                              //variance
  Ry = Ry / 9;                        

  Px = Px + 0.0025;                         
  Kx = Px / (Px + Rx);                      //calculate kalman gains
  agx = agx + Kx * (aax - agx);             
  Px = (1 - Kx) * Px;                       
  Py = Py + 0.0025;
  Ky = Py / (Py + Ry);
  agy = agy + Ky * (aay - agy);
  Py = (1 - Ky) * Py;

  /* kalmen end */
  v_gyrox=-gyrox*1000/loop_time;
}

void D_Motor(int spd){
  spd=spd;
  if (spd > 0) {
    ledcWrite(DChannel_1, LOW);
    ledcWrite(DChannel_2, spd);
  }
  else {
    ledcWrite(DChannel_2, LOW);
    ledcWrite(DChannel_1, -spd);
  }
}


void M_Motor(double spd){
  spd=spd;
  if (abs(euler_angle)>22)spd=0;
  if(spd ==0){digitalWrite(M_SW, LOW);ledcWrite(M_Wheel, 511);}
    else if(spd>0){
      digitalWrite(M_SW, HIGH);
      digitalWrite(M_Dir, HIGH);
      ledcWrite(M_Wheel, 255-spd);
    }
    else {
      digitalWrite(M_SW, HIGH);
      digitalWrite(M_Dir, LOW);
      ledcWrite(M_Wheel, 255+spd);
    }
}


void onConnectedGamepad(GamepadPtr gp) {
    bool foundEmptySlot = false;
    for (int i = 0; i < BP32_MAX_GAMEPADS; i++) {
        if (myGamepads[i] == nullptr) {
            Serial.printf("CALLBACK: Gamepad is connected, index=%d\n", i);
            // Additionally, you can get certain gamepad properties like:
            // Model, VID, PID, BTAddr, flags, etc.
            GamepadProperties properties = gp->getProperties();
            Serial.printf("Gamepad model: %s, VID=0x%04x, PID=0x%04x\n", gp->getModelName().c_str(), properties.vendor_id,
                           properties.product_id);
            myGamepads[i] = gp;
            foundEmptySlot = true;
            break;
        }
    }
    if (!foundEmptySlot) {
        Serial.println("CALLBACK: Gamepad connected, but could not found empty slot");
    }
}


void onDisconnectedGamepad(GamepadPtr gp) {
    bool foundGamepad = false;

    for (int i = 0; i < BP32_MAX_GAMEPADS; i++) {
        if (myGamepads[i] == gp) {
            Serial.printf("CALLBACK: Gamepad is disconnected from index=%d\n", i);
            myGamepads[i] = nullptr;
            foundGamepad = true;
            break;
        }
    }

    if (!foundGamepad) {
        Serial.println("CALLBACK: Gamepad disconnected, but not found in myGamepads");
    }
}

void turn(int position){ledcWrite(servoChannel, map(position, 0, 180, 5, 32));}

void remote(void * parameter){
  while(1){
    BP32.update();
    // It is safe to always do this before using the gamepad API.
    // This guarantees that the gamepad is valid and connected.
    for (int i = 0; i < BP32_MAX_GAMEPADS; i++) {
        GamepadPtr myGamepad = myGamepads[i];

        if (myGamepad && myGamepad->isConnected()) {
            digitalWrite(ledPin,HIGH);
            // There are different ways to query whether a button is pressed.
            // By query each button individually:
            //  a(), b(), x(), y(), l1(), etc...
            if (myGamepad->y() && myGamepad->b()) {
                offset=agx;
                static int colorIdx = 0;
                switch (colorIdx % 3) {
                    case 0:
                        // Red
                        myGamepad->setColorLED(255, 0, 0);
                        break;
                    case 1:
                        // Green
                        myGamepad->setColorLED(0, 255, 0);
                        break;
                    case 2:
                        // Blue
                        myGamepad->setColorLED(0, 0, 255);
                        break;
                }
                colorIdx++;
            }
            if (myGamepad->x()) {
                myGamepad->setRumble(0xc0 /* force */, 0xc0 /* duration */);
            }

            if (myGamepad->throttle()){D_Motor((myGamepad->throttle())/4);}
            else if (myGamepad->brake()){D_Motor(-(myGamepad->brake())/4);}
            else{D_Motor(0);}
            turn(map(myGamepad->axisRX(),-511,511,50,130));
            /*
            Serial.printf(
                "idx=%d, dpad: 0x%02x, buttons: 0x%04x, axis L: %4d, %4d, axis R: %4d, "
                "%4d, brake: %4d, throttle: %4d, misc: 0x%02x\n",
                i,                        // Gamepad Index
                myGamepad->dpad(),        // DPAD
                myGamepad->buttons(),     // bitmask of pressed buttons
                myGamepad->axisX(),       // (-511 - 512) left X Axis
                myGamepad->axisY(),       // (-511 - 512) left Y axis
                myGamepad->axisRX(),      // (-511 - 512) right X axis
                myGamepad->axisRY(),      // (-511 - 512) right Y axis
                myGamepad->brake(),       // (0 - 1023): brake button
                myGamepad->throttle(),    // (0 - 1023): throttle (AKA gas) button
                myGamepad->miscButtons()  // bitmak of pressed "misc" buttons
            );
            */
            // You can query the axis and other properties as well. See Gamepad.h
            // For all the available functions.
        }
    }

    // The main loop must have some kind of "yield to lower priority task" event.
    // Otherwise the watchdog will get triggered.
    // If your main loop doesn't have one, just add a simple `vTaskDelay(1)`.
    // Detailed info here:
    // https://stackoverflow.com/questions/66278271/task-watchdog-got-triggered-the-tasks-did-not-reset-the-watchdog-in-time
    // vTaskDelay(1);
    delay(150);}
}


void Set_K_value() {

  if (Serial.available()) {
    String reading = Serial.readStringUntil('\n');  // read from the Serial Monitor
    /* put your code here*/
    switch (reading[0]){
    case 'a':
      reading[0]=' ';
      reading.trim();
      K1=reading.toFloat();
      Serial.println("k1 = " + String(K1) + ", k2 = " + String(K2) + ", k3 = " + String(K3) + ", k4 = " + String(K4));
      break;
    case 's':
      reading[0]=' ';
      reading.trim();
      K2=reading.toFloat();
      
      Serial.println("k1 = " + String(K1) + ", k2 = " + String(K2) + ", k3 = " + String(K3) + ", k4 = " + String(K4));
      break;
    case 'd':
      reading[0]=' ';
      reading.trim();
      K3=reading.toFloat();
      
      Serial.println("k1 = " + String(K1) + ", k2 = " + String(K2) + ", k3 = " + String(K3) + ", k4 = " + String(K4));
      break;    
    case 'f':
      reading[0]=' ';
      reading.trim();
      K4=reading.toFloat();
      Serial.println("k1 = " + String(K1) + ", k2 = " + String(K2) + ", k3 = " + String(K3) + ", k4 = " + String(K4));
      break; 
    case 'o':
      reading[0]=' ';
      reading.trim();
      offset=reading.toFloat();
      Serial.println("offset = " + String(offset));
      break;
    case 'c': //calibrate
      reading[0]=' ';
      reading.trim();
      offset=agx;
      Serial.println("offset = " + String(offset));
      break;         
    default:
      Serial.println("k1 = " + String(K1) + ", k2 = " + String(K2) + ", k3 = " + String(K3) + ", k4 = " + String(K4));
      break;
      }
  }
}

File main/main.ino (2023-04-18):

#include <ESP32Encoder.h>
#include <Adafruit_MPU6050.h>
#include <Adafruit_Sensor.h>
#include <Wire.h>
#include <PID_v1.h>
//#include <Servo.h>

#define M_PWM 26
#define M_SW 18
#define M_Dir 5
#define D1 33
#define D2 35


ESP32Encoder encoder;
Adafruit_MPU6050 mpu;

const int m_freq = 20000;
const int resolution = 8;
int MAX_PWM_VOLTAGE = 255;
const int M_Wheel = 1;
const int D_1 = 2;
const int D_2 = 3;
const int D_freq = 2000;

double Setpoint, Input, Output;
float kp=80;
float ki=0;
float kd=10;

PID M_PID(&Input, &Output, &Setpoint, kp , ki , kd , DIRECT);// kp ki kd

double offset=0;
double MPU_Input;

void setup() {
  Serial.begin(115200);
  /* M_Wheel setup */
  pinMode(M_SW, OUTPUT);
  pinMode(M_Dir, OUTPUT);
  ledcSetup(M_Wheel , m_freq, resolution);
  ledcAttachPin(M_PWM, M_Wheel);

  ledcSetup(D_1, D_freq, resolution);
  ledcSetup(D_2, D_freq, resolution);
  ledcAttachPin(D1, D_1);
  ledcAttachPin(D2, D_2);
  
  ESP32Encoder::useInternalWeakPullResistors = UP; // Enable the weak pull up resistors
  encoder.attachHalfQuad(19, 23); // Attache pins for use as encoder pins
  encoder.setCount(0);  // set starting count value after attaching


  // Try to initialize the MPU!
  if (!mpu.begin()) {
    Serial.println("Failed to find MPU6050 chip");
    while (1) {delay(10);}}
  Serial.println("MPU6050 Found!");

  mpu.setAccelerometerRange(MPU6050_RANGE_8_G);
  Serial.print("Accelerometer range set to: ");
  switch (mpu.getAccelerometerRange()) {
  case MPU6050_RANGE_2_G:
    Serial.println("+-2G");
    break;
  case MPU6050_RANGE_4_G:
    Serial.println("+-4G");
    break;
  case MPU6050_RANGE_8_G:
    Serial.println("+-8G");
    break;
  case MPU6050_RANGE_16_G:
    Serial.println("+-16G");
    break;
  }

  mpu.setGyroRange(MPU6050_RANGE_500_DEG);
  Serial.print("Gyro range set to: ");
  switch (mpu.getGyroRange()) {
  case MPU6050_RANGE_250_DEG:
    Serial.println("+- 250 deg/s");
    break;
  case MPU6050_RANGE_500_DEG:
    Serial.println("+- 500 deg/s");
    break;
  case MPU6050_RANGE_1000_DEG:
    Serial.println("+- 1000 deg/s");
    break;
  case MPU6050_RANGE_2000_DEG:
    Serial.println("+- 2000 deg/s");
    break;
  }

  mpu.setFilterBandwidth(MPU6050_BAND_5_HZ);
  Serial.print("Filter bandwidth set to: ");
  switch (mpu.getFilterBandwidth()) {
  case MPU6050_BAND_260_HZ:
    Serial.println("260 Hz");
    break;
  case MPU6050_BAND_184_HZ:
    Serial.println("184 Hz");
    break;
  case MPU6050_BAND_94_HZ:
    Serial.println("94 Hz");
    break;
  case MPU6050_BAND_44_HZ:
    Serial.println("44 Hz");
    break;
  case MPU6050_BAND_21_HZ:
    Serial.println("21 Hz");
    break;
  case MPU6050_BAND_10_HZ:
    Serial.println("10 Hz");
    break;
  case MPU6050_BAND_5_HZ:
    Serial.println("5 Hz");
    break;
  }
  Serial.println("");
  delay(100);


/*PID Controller*/
  Input=0;
  Setpoint=0;
  M_PID.SetMode(AUTOMATIC);
  M_PID.SetOutputLimits(-255,255);
  M_PID.SetSampleTime(10);

  sensors_event_t a, g, temp;
  mpu.getEvent(&a, &g, &temp);
  offset=a.acceleration.x;
}

void loop() {
  if (Serial.available()) {
    String reading = Serial.readStringUntil('\n');  // read from the Serial Monitor
    /* put your code here*/
    switch (reading[0]){
    case 'p':
      reading[0]=' ';
      reading.trim();
      kp=reading.toFloat();
      M_PID.SetTunings(kp, ki, kd);
      Serial.println("kp = " + String(kp) + ", ki = " + String(ki) + ", kd = " + String(kd));
      break;
    case 'i':
      reading[0]=' ';
      reading.trim();
      ki=reading.toFloat();
      M_PID.SetTunings(kp, ki, kd);
      Serial.println("kp = " + String(kp) + ", ki = " + String(ki) + ", kd = " + String(kd));
      break;
    case 'd':
      reading[0]=' ';
      reading.trim();
      kd=reading.toFloat();
      M_PID.SetTunings(kp, ki, kd);
      Serial.println("kp = " + String(kp) + ", ki = " + String(ki) + ", kd = " + String(kd));
      break;    
    default:
      Serial.println("kp = " + String(kp) + ", ki = " + String(ki) + ", kd = " + String(kd));
      break;
      }
  }



  sensors_event_t a, g, temp;
  mpu.getEvent(&a, &g, &temp);
  MPU_Input=(a.acceleration.x-offset)*1;
  /* Print out the values */
  Serial.print("Acceleration: ");
//  Serial.println(MPU_Input);
  Serial.println(Output);
  Serial.print("");
  //M_Motor(a.acceleration.x*20);

  Self_Balancing(MPU_Input);
}

void M_Motor(double spd){
  spd=spd;
  if(spd ==0){digitalWrite(M_SW, LOW);}
    else if(spd>0){
      digitalWrite(M_SW, HIGH);
      digitalWrite(M_Dir, HIGH);
      ledcWrite(M_Wheel, 255-spd);
    }
    else {
      digitalWrite(M_SW, HIGH);
      digitalWrite(M_Dir, LOW);
      ledcWrite(M_Wheel, 255+spd);
    }
}

void D_Motor(int speed){
  if (speed > 0) {
    ledcWrite(D_1, LOW);
    ledcWrite(D_2, speed);
  }
  else if (speed == 0){
    ledcWrite(D_1, LOW);
    ledcWrite(D_2, LOW);
  }
  else {
    ledcWrite(D_2, LOW);
    ledcWrite(D_1, speed);
  }

}
void turning(int degree){

}

void Self_Balancing(double input){
  Input = input;
  M_PID.Compute();
  M_Motor(Output);
}

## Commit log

2023-04-09 motor open loop control
2023-04-14 updated servo
2023-04-19 kalman filter added
2023-04-23 schematic added
2023-04-24 STL and CAD files aefiles added
    [Assem1 - Battery-3.STL, Assem1 - Belt^Assem1-1.STL, Assem1 - BigGear^Assem1-1.STL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]
